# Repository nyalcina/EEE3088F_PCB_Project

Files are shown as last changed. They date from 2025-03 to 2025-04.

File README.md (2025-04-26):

# EEE3088F_PCB_Project_PTXNYA001_MNGAMO004
This repository details the progress of a Micromouse Power Board which was assigned by the EEE3088F teaching staff of the University of Cape Town. This project was completed in collaboration between Nyakallo Peete and Amos Manganye.
# Micro-Mouse Power Subsystem




---

## Overview

This repository contains the design files, schematics, and documentation for the **Power Subsystem** of the 2025 Micro-Mouse Project, developed as part of the EEE3088F course.

The Power Subsystem is responsible for:
- Accepting 9V input from a USB-C Power Delivery (PD) source.
- Charging a 3.7V 800mAh LiPo battery with selectable charging modes.
- Supplying regulated 3.3V and 5V outputs to system modules and motors.
- Controlling system power states through a low-leakage ON/OFF switch.
- Monitoring battery voltage and current via an I²C bus.
- Driving four motors (primary and auxiliary) for micro-mouse navigation.

---

## Features

- Provides regulated 5V and 3.3V outputs to supply all system modules, including processors, sensors, and external loads.
- Powers four motors (bidirectionally) via integrated motor driver outputs for primary and auxiliary drive control.
- Supports charging of a 3.7V 800mAh LiPo battery from a 9V USB-C input.
- Offers two selectable battery charging modes: low current mode (for extended battery life) and high current mode (for faster charging).
- Includes an ON/OFF control system that completely disables power rails when not in use, reducing standby current to less than 30μA.
- Enables real-time battery voltage and current monitoring through an I²C interface for improved system diagnostics and safety.
- Provides jumper-based power isolation and multiple test points throughout the system to simplify testing, debugging, and future upgrades.
- Designed for compact size, robustness, low cost, and manufacturability using JLCPCB basic part components.

---

## Tools Used

- KiCad 9.0 for schematic and PCB layout
- EasyEDA for footprints
- GitHub for version control and project documentation
- JLCBPB for manufacturing

---

## Authors

- **Amos Manganye**
- **Nyakallo Peete**

---

## Acknowledgements

- University of Cape Town (UCT) — Department of Electrical Engineering
- EEE3088F Teaching Staff

---

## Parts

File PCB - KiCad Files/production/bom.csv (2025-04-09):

Designator | Footprint | Quantity | Value | LCSC Part #
C10, C15 | 0603 | 2 | 100n | C14663
C11, C5, C8, C9 | 0603 | 4 | 100n | C14663
C12, C13, C16, C17, C23, C3 | 0603 | 6 | 10u | C19702
C14, C2 | 0603 | 2 | 2.2u | C23630
C19, C22, C24, C25 | 0603 | 4 | 10u | C19702
C21, C4 | 0603 | 2 | 1u | C5673
C27, C28, C29, C30, C31, C32 | 0603 | 6 | 22u | C59461
C6, C7 | 0603 | 2 | 10u | C19702
D1, D2, D4, D5 | 0603 | 4 | LED | C2286
D3 | 0603 | 1 | Red | C2286
J1 | JST_PH_S2B-PH-K_1x02_P2.00mm_Horizontal | 1 | Conn_01x02_Pin
J3 | PinHeader_2x16_P2.54mm_Vertical | 1 | Conn_02x16_Odd_Even
J4 | USB-C-SMD_TYPE-602-T3 | 1 | USB_C_Receptacle_PowerOnly_6P | C2927028
JP10, JP15, JP17, JP18, JP19, JP20, JP21, JP22, JP23, JP24, JP25, JP26, JP9 | SolderJumper-2_P1.3mm_Open_Pad1.0x1.5mm | 13 | Jumper_2_Small_Open
L1, L2 | 1008 | 2 | 2.2u | C5832372
R10 | 0603 | 1 | 56k | C23206
R11 | 0603 | 1 | 82k | C23254
R12, R22, R23, R8, R9 | 0603 | 5 | 0.22 | C3013347
R13 | 0805 | 1 | 5k6 | C4382
R14, R16, R19, R20, R28, R5 | 0603 | 6 | 1k | C21190
R2, R32, R33 | 0603 | 3 | 510k | C23192
R24, R27 | 0603 | 2 | 4.7k | C23162
R25 | 0603 | 1 | 1k8 | C4177
R29 | 0805 | 1 | 6k8 | C17772
R30, R31, R34, R6 | 0805 | 4 | 10k | C17414
R4 | 0805 | 1 | 470k | C17709
R7 | 0805 | 1 | 8.2k | C17828
SW1 | SW-TH_1MS1T1B1M1QES-5 | 1 | SW_Nidec_CAS-120A1 | C496154
TP19, TP2, TP20, TP21, TP22, TP24, TP25, TP3, TP32, TP33, TP34, TP35, TP36, TP37, TP38, TP39, TP4, TP40 | TestPoint_Pad_D1.0mm | 18 | TestPoint
U1 | IC_DRV8833PWPR | 1 | DRV8833PWPR | C50506
U10, U11 | TPS63020DSJR | 2 | TPS63020 | C15483
U13 | ESSOP-10_L4.9-W3.9-P1.0-LS6.0-TL-EP | 1 | CH224K | C970725
U2 | INA219AIDCNR | 1 | INA219AxDCN | C87469
U3, U5 | SOT-23-6_L2.9-W1.6-P0.95-LS2.8-BR | 2 | TPS22917DBV | C2681320
U4 | IC_DRV8833PWPR | 1 | DRV8833PWP | C50506
U6 | SOT-23-6_L2.9-W1.6-P0.95-LS2.8-BR | 1 | TS5A3159ADBVR | C128405
U9 | ESOP-8_L4.9-W3.9-P1.27-LS6.0-BL-EP | 1 | TP4056-42-ESOP8 | C16581

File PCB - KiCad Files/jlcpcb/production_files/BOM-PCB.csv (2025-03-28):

Comment | Designator | Footprint | LCSC | Quantity
100n | C10,C15 | C_0603_1608Metric_Pad1.08x0.95mm_HandSolder | C14663 | 2
TPS63020 | U10,U11 | TPS63020DSJR | C15483 | 2
47u | C8,C9 | C_0805_2012Metric_Pad1.18x1.45mm_HandSolder | C16780 | 2
10k | R30,R31,R32,R6 | R_0805_2012Metric_Pad1.20x1.40mm_HandSolder | C17414 | 4
6k8 | R29 | R_0805_2012Metric_Pad1.20x1.40mm_HandSolder | C17772 | 1
8.2k | R7 | R_0805_2012Metric_Pad1.20x1.40mm_HandSolder | C17828 | 1
10u | C11,C12,C3 | C_0603_1608Metric_Pad1.08x0.95mm_HandSolder | C197002 | 3
10u | C14,C19,C22 | C_0603_1608Metric_Pad1.08x0.95mm_HandSolder | C19702 | 3
1k | R14,R16,R28,R5 | R_0603_1608Metric_Pad0.98x0.95mm_HandSolder | C21190 | 4
LED | D1,D3,D4 | LED_0603_1608Metric_Pad1.05x0.95mm_HandSolder | C2286 | 3
4.7k | R24,R27 | R_0603_1608Metric_Pad0.98x0.95mm_HandSolder | C23162 | 2
2.2u | C16 | C_0603_1608Metric_Pad1.08x0.95mm_HandSolder | C23630 | 1
USB_C_Receptacle_PowerOnly_6P | J4 | USB_C_Receptacle_GCT_USB4110 | C2927028 | 1
200 | R10 | R_0805_2012Metric_Pad1.20x1.40mm_HandSolder | C2933534 | 1
1k8 | R25 | R_0603_1608Metric_Pad0.98x0.95mm_HandSolder | C4177 | 1
5k6 | R13 | R_0805_2012Metric_Pad1.20x1.40mm_HandSolder | C4382 | 1
SW_Nidec_CAS-120A1 | SW1 | SW-TH_1MS1T1B1M1QES-5 | C496154 | 1
DRV8833PWPR | U1,U4 | DRV8833PWPR | C50506 | 2
1u | C21,C4 | C_0603_1608Metric_Pad1.08x0.95mm_HandSolder | C5673 | 2
INA219AxDCN | U2 | INA219AIDCNR | C87469 | 1
2.2u | C13,C17 | C_0603_1608Metric_Pad1.08x0.95mm_HandSolder | C96446 | 2
TestPoint | TP36 | TestPoint_Pad_D1.0mm |  | 1
TestPoint | TP35 | TestPoint_Pad_D1.0mm |  | 1
TestPoint | TP34 | TestPoint_Pad_D1.0mm |  | 1
TestPoint | TP33 | TestPoint_Pad_D1.0mm |  | 1
TestPoint | TP32 | TestPoint_Pad_D1.0mm |  | 1
TestPoint | TP30 | TestPoint_Pad_D1.0mm |  | 1
TestPoint | TP26 | TestPoint_Pad_D1.0mm |  | 1
TestPoint | TP25 | TestPoint_Pad_D1.0mm |  | 1
TestPoint | TP24 | TestPoint_Pad_D1.0mm |  | 1
TestPoint | TP23 | TestPoint_Pad_D1.0mm |  | 1
TestPoint | TP22 | TestPoint_Pad_D1.0mm |  | 1
TestPoint | TP21 | TestPoint_Pad_D1.0mm |  | 1
TestPoint | TP20 | TestPoint_Pad_D1.0mm |  | 1
TestPoint | TP19 | TestPoint_Pad_D1.0mm |  | 1
TestPoint | TP14 | TestPoint_Pad_D1.0mm |  | 1
TestPoint | TP13 | TestPoint_Pad_D1.0mm |  | 1
TestPoint | TP12 | TestPoint_Pad_D1.0mm |  | 1
TestPoint | TP11 | TestPoint_Pad_D1.0mm |  | 1
TestPoint | TP10 | TestPoint_Pad_D1.0mm |  | 1
TestPoint | TP9 | TestPoint_Pad_D1.0mm |  | 1
TestPoint | TP8 | TestPoint_Pad_D1.0mm |  | 1
TestPoint | TP7 | TestPoint_Pad_D1.0mm |  | 1
TestPoint | TP6 | TestPoint_Pad_D1.0mm |  | 1
TestPoint | TP4 | TestPoint_Pad_D1.0mm |  | 1
TestPoint | TP3 | TestPoint_Pad_D1.0mm |  | 1
TestPoint | TP2 | TestPoint_Pad_D1.0mm |  | 1
0.22 | R12 | R2512 |  | 1
200 | R11 | R_0805_2012Metric_Pad1.20x1.40mm_HandSolder |  | 1
1.8k | R4 | R_0603_1608Metric |  | 1
1.8k | R2 | R_0603_1608Metric |  | 1
2.2u | L2 | L_1008_2520Metric_Pad1.43x2.20mm_HandSolder |  | 1
2.2u | L1 | L_1008_2520Metric_Pad1.43x2.20mm_HandSolder |  | 1
Jumper_2_Small_Open | JP18 | SolderJumper-2_P1.3mm_Open_Pad1.0x1.5mm |  | 1
Jumper_2_Small_Open | JP16 | SolderJumper-2_P1.3mm_Open_Pad1.0x1.5mm |  | 1
Jumper_2_Small_Open | JP15 | SolderJumper-2_P1.3mm_Open_Pad1.0x1.5mm |  | 1
Jumper_2_Small_Open | JP14 | SolderJumper-2_P1.3mm_Open_Pad1.0x1.5mm |  | 1
Jumper_2_Small_Open | JP11 | SolderJumper-2_P1.3mm_Open_Pad1.0x1.5mm |  | 1
Jumper_2_Small_Open | JP10 | SolderJumper-2_P1.3mm_Open_Pad1.0x1.5mm |  | 1
Jumper_2_Small_Open | JP9 | SolderJumper-2_P1.3mm_Open_Pad1.0x1.5mm |  | 1
Jumper_2_Small_Open | JP8 | SolderJumper-2_P1.3mm_Open_Pad1.0x1.5mm |  | 1
Jumper_2_Small_Open | JP7 | SolderJumper-2_P1.3mm_Open_Pad1.0x1.5mm |  | 1
Jumper_2_Small_Open | JP6 | SolderJumper-2_P1.3mm_Open_Pad1.0x1.5mm |  | 1
Jumper_2_Small_Open | JP5 | SolderJumper-2_P1.3mm_Open_Pad1.0x1.5mm |  | 1
Jumper_2_Small_Open | JP4 | SolderJumper-2_P1.3mm_Open_Pad1.0x1.5mm |  | 1
Jumper_2_Small_Open | JP3 | SolderJumper-2_P1.3mm_Open_Pad1.0x1.5mm |  | 1
Jumper_2_Small_Open | JP2 | SolderJumper-2_P1.3mm_Open_Pad1.0x1.5mm |  | 1
Jumper_2_Small_Open | JP1 | SolderJumper-2_P1.3mm_Open_Pad1.0x1.5mm |  | 1
Conn_02x16_Odd_Even | J3 | PinHeader_2x16_P2.54mm_Vertical |  | 1
Conn_01x02_Pin | J1 | JST_JWPF_B02B-JWPF-SK-R_1x02_P2.00mm_Vertical |  | 1
10u | C7 | C_0603_1608Metric_Pad1.08x0.95mm_HandSolder |  | 1
10u | C6 | C_0603_1608Metric_Pad1.08x0.95mm_HandSolder |  | 1
0.1u | C5 | C_0603_1608Metric_Pad1.08x0.95mm_HandSolder |  | 1
2.2u | C2 | C_0603_1608Metric_Pad1.08x0.95mm_HandSolder |  | 1
TestPoint | TP40 | TestPoint_Pad_D1.0mm |  | 1
TestPoint | TP39 | TestPoint_Pad_D1.0mm |  | 1
TestPoint | TP38 | TestPoint_THTPad_D2.5mm_Drill1.2mm |  | 1
TestPoint | TP37 | TestPoint_THTPad_D2.5mm_Drill1.2mm |  | 1
TestPoint | TP27 | TestPoint_Pad_D1.0mm |  | 1
0.22 | R19 | R2512 |  | 1
0.22 | R18 | R2512 |  | 1
0.22 | R17 | R2512 |  | 1
0.22 | R15 | R2512 |  | 1
0.22 | R9 | R2512 |  | 1
0.22 | R8 | R2512 |  | 1
Jumper_2_Small_Open | JP24 | SolderJumper-2_P1.3mm_Open_Pad1.0x1.5mm |  | 1
Jumper_2_Small_Open | JP23 | SolderJumper-2_P1.3mm_Open_Pad1.0x1.5mm |  | 1
Jumper_2_Small_Open | JP22 | SolderJumper-2_P1.3mm_Open_Pad1.0x1.5mm |  | 1
Jumper_2_Small_Open | JP21 | SolderJumper-2_P1.3mm_Open_Pad1.0x1.5mm |  | 1
Jumper_2_Small_Open | JP19 | SolderJumper-2_P1.3mm_Open_Pad1.0x1.5mm |  | 1
Jumper_2_Small_Open | JP17 | SolderJumper-2_P1.3mm_Open_Pad1.0x1.5mm |  | 1

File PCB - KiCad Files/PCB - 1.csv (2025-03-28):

Reference | Qty | Value | DNP | Exclude from BOM | Exclude from Board | Footprint | Datasheet
C2,C13,C16,C17 | 4 | 2.2u |  |  |  | Capacitor_SMD:C_0603_1608Metric_Pad1.08x0.95mm_HandSolder | https://jlcpcb.com/api/file/downloadByFileSystemAccessId/8568525238768373760
C3,C6,C7,C11,C12,C14,C19,C22 | 8 | 10u |  |  |  | Capacitor_SMD:C_0603_1608Metric_Pad1.08x0.95mm_HandSolder | https://jlcpcb.com/api/file/downloadByFileSystemAccessId/8579707107920437248,https://jlcpcb.com/api/file/downloadByFileSystemAccessId/8579707359440130048,~
C4,C21 | 2 | 1u |  |  |  | Capacitor_SMD:C_0603_1608Metric_Pad1.08x0.95mm_HandSolder | https://jlcpcb.com/api/file/downloadByFileSystemAccessId/8579707343598243840,https://jlcpcb.com/api/file/downloadByFileSystemAccessId/8586178237072617472
C5 | 1 | 0.1u |  |  |  | Capacitor_SMD:C_0603_1608Metric_Pad1.08x0.95mm_HandSolder | ~
C8,C9 | 2 | 47u |  |  |  | Capacitor_SMD:C_0805_2012Metric_Pad1.18x1.45mm_HandSolder | ~
C10,C15 | 2 | 100n |  |  |  | Capacitor_SMD:C_0603_1608Metric_Pad1.08x0.95mm_HandSolder | ~
D1,D4 | 2 | LED |  |  |  | LED_SMD:LED_0603_1608Metric_Pad1.05x0.95mm_HandSolder | https://jlcpcb.com/api/file/downloadByFileSystemAccessId/8550723991833485312
D3 | 1 | Red |  |  |  | LED_SMD:LED_0603_1608Metric_Pad1.05x0.95mm_HandSolder | https://jlcpcb.com/api/file/downloadByFileSystemAccessId/8550723991833485312
J1 | 1 | Conn_01x02_Pin |  |  |  | Connector_JST:JST_JWPF_B02B-JWPF-SK-R_1x02_P2.00mm_Vertical | ~
J3 | 1 | Conn_02x16_Odd_Even |  |  |  | Connector_PinHeader_2.54mm:PinHeader_2x16_P2.54mm_Vertical | ~
J4 | 1 | USB_C_Receptacle_PowerOnly_6P |  |  |  | Connector_USB:USB_C_Receptacle_GCT_USB4110 | https://jlcpcb.com/api/file/downloadByFileSystemAccessId/8589784804343648256
JP1,JP2,JP3,JP4,JP5,JP6,JP7,JP8,JP9,JP10,JP11,JP14,JP15,JP16,JP17,JP18,JP19,JP21,JP22,JP23,JP24 | 21 | Jumper_2_Small_Open |  |  |  | Jumper:SolderJumper-2_P1.3mm_Open_Pad1.0x1.5mm | ~
JP13 | 1 | Jumper_3_Open |  | Excluded from BOM |  |  | ~
L1,L2 | 2 | 2.2u |  |  |  | Inductor_SMD:L_1008_2520Metric_Pad1.43x2.20mm_HandSolder | ~
R2,R4 | 2 | 1.8k |  |  |  | Resistor_SMD:R_0603_1608Metric | ~
R5,R14,R16,R28 | 4 | 1k |  |  |  | Resistor_SMD:R_0603_1608Metric_Pad0.98x0.95mm_HandSolder | https://jlcpcb.com/api/file/downloadByFileSystemAccessId/8579705924167974912,https://jlcpcb.com/api/file/downloadByFileSystemAccessId/8579706098733010944
R6,R30,R31,R32 | 4 | 10k |  |  |  | Resistor_SMD:R_0805_2012Metric_Pad1.20x1.40mm_HandSolder | https://jlcpcb.com/api/file/downloadByFileSystemAccessId/8550723991833485312,https://jlcpcb.com/api/file/downloadByFileSystemAccessId/8562006748401074176,http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
R7 | 1 | 8.2k |  |  |  | Resistor_SMD:R_0805_2012Metric_Pad1.20x1.40mm_HandSolder | https://jlcpcb.com/api/file/downloadByFileSystemAccessId/8579705924167974912
R8,R9,R12,R15,R17,R18,R19 | 7 | 0.22 |  |  |  | Library:R2512 | ~
R10,R11 | 2 | 200 |  |  |  | Resistor_SMD:R_0805_2012Metric_Pad1.20x1.40mm_HandSolder | ~
R13 | 1 | 5k6 |  |  |  | Resistor_SMD:R_0805_2012Metric_Pad1.20x1.40mm_HandSolder | https://jlcpcb.com/api/file/downloadByFileSystemAccessId/8579706617560436736
R24,R27 | 2 | 4.7k |  |  |  | Resistor_SMD:R_0603_1608Metric_Pad0.98x0.95mm_HandSolder | https://jlcpcb.com/api/file/downloadByFileSystemAccessId/8579706098733010944
R25 | 1 | 1k8 |  |  |  | Resistor_SMD:R_0603_1608Metric_Pad0.98x0.95mm_HandSolder | https://jlcpcb.com/api/file/downloadByFileSystemAccessId/8579706147000926208
R29 | 1 | 6k8 |  |  |  | Resistor_SMD:R_0805_2012Metric_Pad1.20x1.40mm_HandSolder | https://jlcpcb.com/api/file/downloadByFileSystemAccessId/8579706637797543936
SW1 | 1 | SW_Nidec_CAS-120A1 |  |  |  | Library:SW-TH_1MS1T1B1M1QES-5 | https://www.nidec-components.com/e/catalog/switch/cas.pdf
TP2,TP3,TP4,TP6,TP7,TP8,TP9,TP10,TP11,TP12,TP13,TP14,TP19,TP20,TP21,TP22,TP23,TP24,TP25,TP26,TP27,TP30,TP32,TP33,TP34,TP35,TP36,TP39,TP40 | 29 | TestPoint |  |  |  | TestPoint:TestPoint_Pad_D1.0mm | ~
TP37,TP38 | 2 | TestPoint |  |  |  | TestPoint:TestPoint_THTPad_D2.5mm_Drill1.2mm | ~
U1 | 1 | DRV8833PWPR |  |  |  | Library:DRV8833PWPR | https://jlcpcb.com/api/file/downloadByFileSystemAccessId/8588881461298802689
U2 | 1 | INA219AxDCN |  |  |  | Library:INA219AIDCNR | https://jlcpcb.com/api/file/downloadByFileSystemAccessId/8586200525100486656
U3,U5 | 2 | TPS22917DBV |  |  |  | Nhlamolo.:SOT-23-6_L2.9-W1.6-P0.95-LS2.8-BR | http://www.ti.com/lit/ds/symlink/tps22917.pdf
U4 | 1 | DRV8833PWP |  |  |  | Package_SO:HTSSOP-16-1EP_4.4x5mm_P0.65mm_EP3.4x5mm_Mask2.46x2.31mm_ThermalVias | https://jlcpcb.com/api/file/downloadByFileSystemAccessId/8588881461298802689
U9 | 1 | TP4056-42-ESOP8 |  |  |  | Nhlamolo.:ESOP-8_L4.9-W3.9-P1.27-LS6.0-BL-EP-1 | https://www.lcsc.com/datasheet/lcsc_datasheet_2410121619_TOPPOWER-Nanjing-Extension-Microelectronics-TP4056-42-ESOP8_C16581.pdf
U10,U11 | 2 | TPS63020 |  |  |  | Library:TPS63020DSJR | chrome-https://jlcpcb.com/api/file/downloadByFileSystemAccessId/8588881940225540096
U12 | 1 | TS5A3159ADBVR |  |  |  | Nhlamolo.:SOT-23-6_L2.9-W1.6-P0.95-LS2.8-BR | http://www.ti.com/lit/ds/symlink/ts5a3159a.pdf
U13 | 1 | CH224K |  |  |  | Nhlamolo.:ESSOP-10_L4.9-W3.9-P1.0-LS6.0-TL-EP | https://jlcpcb.com/api/file/downloadByFileSystemAccessId/8588893165608296448

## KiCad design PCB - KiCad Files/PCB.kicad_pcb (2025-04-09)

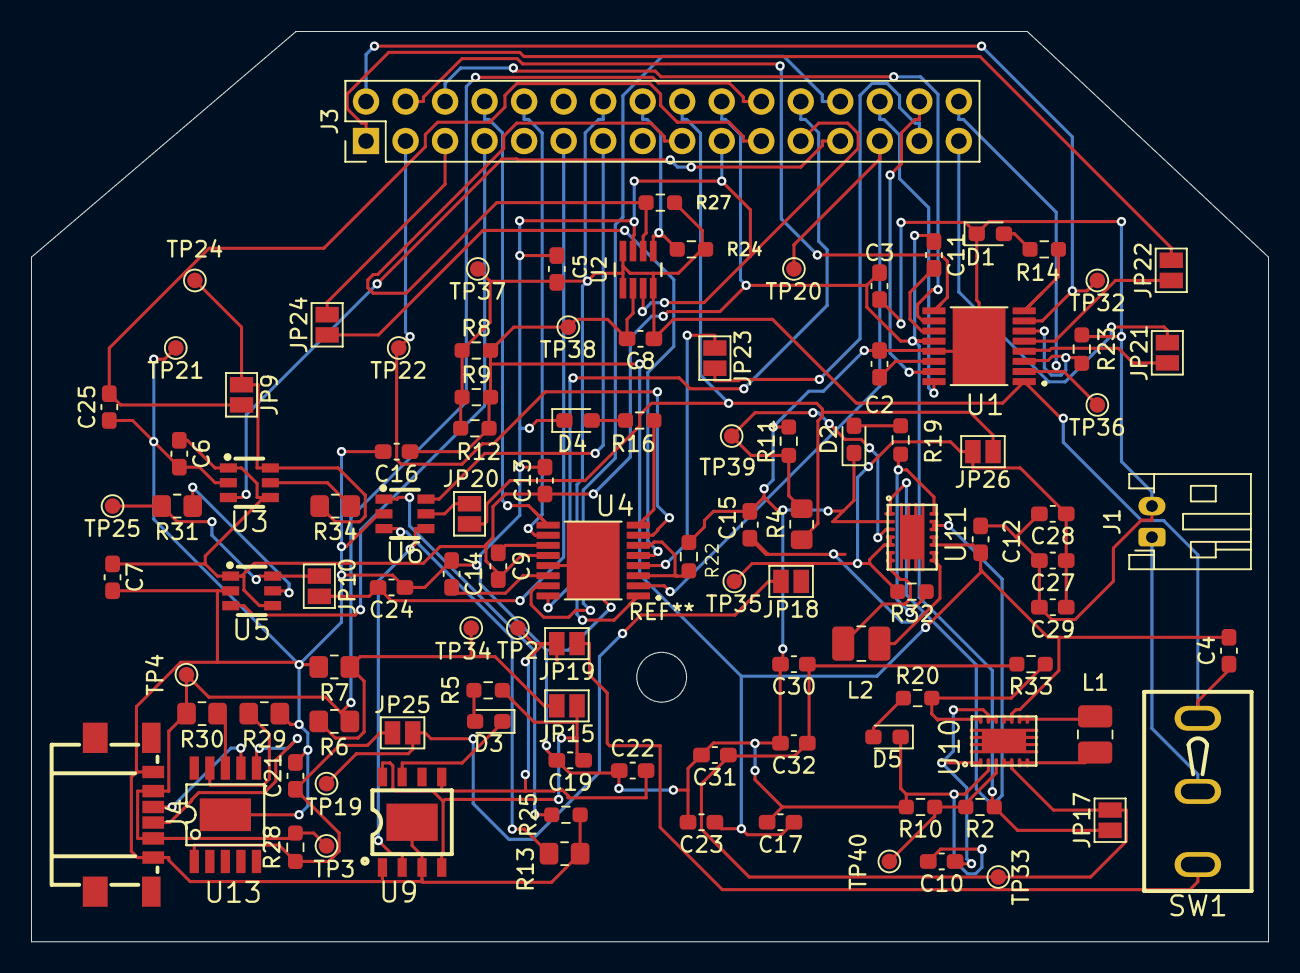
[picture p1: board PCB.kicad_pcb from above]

Board: 2 copper layers, 79.5 x 58.5 mm, 107 parts (0 on the bottom side), 78 nets.

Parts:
C2, C14: 2.2u; C_0603_1608Metric_Pad1.08x0.95mm_HandSolder
C3, C6, C7, C12, C13, C16, C17, C19, C22, C23, C24, C25: 10u; C_0603_1608Metric_Pad1.08x0.95mm_HandSolder
C4, C21: 1u; C_0603_1608Metric_Pad1.08x0.95mm_HandSolder
C5, C8, C9, C10, C11, C15: 100n; C_0603_1608Metric_Pad1.08x0.95mm_HandSolder
C27, C28, C29, C30, C31, C32: 22u; C_0603_1608Metric_Pad1.08x0.95mm_HandSolder
D1, D2, D4, D5: LED; LED_0603_1608Metric_Pad1.05x0.95mm_HandSolder
D3: Red; LED_0603_1608Metric_Pad1.05x0.95mm_HandSolder
J1: Conn_01x02_Pin; JST_PH_S2B-PH-K_1x02_P2.00mm_Horizontal
J3: Conn_02x16_Odd_Even; PinHeader_2x16_P2.54mm_Vertical
J4: USB_C_Receptacle_PowerOnly_6P; USB-C-SMD_TYPE-602-T3
JP9, JP10, JP15, JP17, JP18, JP19, JP20, JP21, JP22, JP23, JP24, JP25, JP26: Jumper_2_Small_Open; SolderJumper-2_P1.3mm_Open_Pad1.0x1.5mm
L1, L2: 2.2u; L_1008_2520Metric_Pad1.43x2.20mm_HandSolder
R2, R32, R33: 510k; R_0603_1608Metric_Pad0.98x0.95mm_HandSolder
R4: 470k; R_0805_2012Metric_Pad1.20x1.40mm_HandSolder
R5, R14, R16, R19, R20, R28: 1k; R_0603_1608Metric_Pad0.98x0.95mm_HandSolder
R6, R30, R31, R34: 10k; R_0805_2012Metric_Pad1.20x1.40mm_HandSolder
R7: 8.2k; R_0805_2012Metric_Pad1.20x1.40mm_HandSolder
R8, R9, R12, R22, R23: 0.22; R_0603_1608Metric_Pad0.98x0.95mm_HandSolder
R10: 56k; R_0603_1608Metric_Pad0.98x0.95mm_HandSolder
R11: 82k; R_0603_1608Metric_Pad0.98x0.95mm_HandSolder
R13: 5k6; R_0805_2012Metric_Pad1.20x1.40mm_HandSolder
R24, R27: 4.7k; R_0603_1608Metric_Pad0.98x0.95mm_HandSolder
R25: 1k8; R_0603_1608Metric_Pad0.98x0.95mm_HandSolder
R29: 6k8; R_0805_2012Metric_Pad1.20x1.40mm_HandSolder
SW1: SW_Nidec_CAS-120A1; SW-TH_1MS1T1B1M1QES-5
TP2, TP3, TP4, TP19, TP20, TP21, TP22, TP24, TP25, TP32, TP33, TP34, TP35, TP36, TP37, TP38, TP39, TP40: TestPoint; TestPoint_Pad_D1.0mm
U1: DRV8833PWPR; IC_DRV8833PWPR
U2: INA219AxDCN; INA219AIDCNR
U3, U5: TPS22917DBV; SOT-23-6_L2.9-W1.6-P0.95-LS2.8-BR
U4: DRV8833PWP; IC_DRV8833PWPR
U6: TS5A3159ADBVR; SOT-23-6_L2.9-W1.6-P0.95-LS2.8-BR
U9: TP4056-42-ESOP8; ESOP-8_L4.9-W3.9-P1.27-LS6.0-BL-EP
U10, U11: TPS63020; TPS63020DSJR
U13: CH224K; ESSOP-10_L4.9-W3.9-P1.0-LS6.0-TL-EP

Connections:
3V3 Out: J3.18, JP20.1 (A), JP26.1 (A), R4.1
5V Out: C3.1, C6.1, C7.1, C9.1, C11.1, C13.1, J3.20, JP17.1 (A), R2.1, U1.12 (VM), U3.1 (VIN), U3.4 (CT), U4.12 (VM), U5.1 (VIN), U5.4 (CT)
/3V3_Out: JP18.2 (B), JP25.2 (B), TP19.1
/CC1: J4.A5 (CC1), U13.7 (CC1)
/CC2: J4.B5 (CC2), U13.6 (CC2)
/M1AO2: JP21.1 (A), U1.4 (AOUT2)
/M2BO2: JP22.1 (A), U1.5 (BOUT2)
/M3AO2: JP23.1 (A), U4.4 (AOUT2)
/M4BO2: JP24.1 (A), U4.5 (BOUT2)
/SEN1: R23.2, U1.3 (AISEN), U1.6 (BISEN)
/SEN2: R22.2, U4.3 (AISEN), U4.6 (BISEN)
Battery: C4.1, C5.1, C8.1, J3.14, R8.1, R9.1, R12.1, R24.1, R27.1, SW1.1 (C), TP37.1, U1.1 (~SLEEP), U2.1 (IN+), U2.4 (VS), U2.8 (A1), U4.1 (~SLEEP)
CTRL_EXT_LOAD1: J3.25, U3.3 (ON)
CTRL_EXT_LOAD2: J3.7, U5.3 (ON)
Charger: JP19.1 (A), SW1.3 (A)
EXT_LOAD1_OUT: C25.2, J3.21, JP9.2 (B)
EXT_LOAD2_OUT: C24.2, J3.11, JP10.2 (B)
FAST_CHARGE_CTRL: J3.13, U6.6 (IN)
GND: C2.1, C3.2, C5.2, C6.2, C7.2, C10.2, C12.2, C13.2, C14.1, C15.2, C16.2, C17.2, C19.2, C21.2, C22.1, C23.2, C24.1, C25.1, C27.2, C28.2, C29.2, C30.2, C31.2, C32.2, D1.1 (K), D2.1 (K), D4.1 (K), D5.1 (K), J1.2, J3.19, J3.23, J4.A12 (GND), J4.B12 (GND), R7.2, R10.2, R11.2, R13.1, R22.1, R23.1, R25.1, R29.1, TP21.1, U1.13 (GND), U1.17 (GND), U2.3 (GND), U2.7 (A0), U3.2 (GND), U4.13 (GND), U4.17 (GND), U5.2 (GND), U6.2 (GND), U9.1 (TEMP), U9.3 (GND), U9.9 (EPAD), U10.2 (GND), U11.2 (GND), U13.11 (GND)
High_Voltage_(9V): J3.22, J4.A9 (VBUS), J4.B9 (VBUS), R6.1, R28.1, R30.2, TP3.1, TP4.1
I2C1_SCL: J3.16, R24.2, U2.5 (SCL)
I2C1_SDA: J3.17, R27.2, U2.6 (SDA)
Load_Supply: C4.2, C8.2, C12.1, C16.1, C17.1, C23.1, R8.2, R9.2, R12.2, TP38.1, U2.2 (IN-), U10.10 (VIN2), U10.11 (VIN1), U11.10 (VIN2), U11.11 (VIN1)
MOTOR1_A_OUT: J3.32, TP36.1, U1.2 (AOUT1)
MOTOR1_B_OUT: J3.31, JP21.2 (B)
MOTOR1_CTRL1: J3.28, U1.16 (AIN1)
MOTOR1_CTRL2: J3.30, U1.15 (AIN2)
MOTOR2_A_OUT: J3.2, TP32.1, U1.7 (BOUT1)
MOTOR2_B_OUT: J3.1, JP22.2 (B)
MOTOR2_CTRL1: J3.4, U1.9 (BIN1)
MOTOR2_CTRL2: J3.6, U1.10 (BIN2)
MOTOR3_A_OUT: J3.27, TP20.1, U4.2 (AOUT1)
MOTOR3_B_OUT: J3.29, JP23.2 (B)
MOTOR3_CTRL1: J3.24, U4.16 (AIN1)
MOTOR3_CTRL2: J3.26, U4.15 (AIN2)
MOTOR4_A_OUT: J3.3, TP22.1, U4.7 (BOUT1)
MOTOR4_B_OUT: J3.5, JP24.2 (B)
MOTOR4_CTRL1: J3.8, U4.9 (BIN1)
MOTOR4_CTRL2: J3.10, U4.10 (BIN2)
unnamed: D1.2 (A), R14.1
unnamed: D2.2 (A), R19.1
unnamed: D3.2 (A), R5.2
unnamed: D3.1 (K), U9.7 (~CHRG)
unnamed: D4.2 (A), R16.1
unnamed: D5.2 (A), R20.1
unnamed: J1.1, SW1.2 (B)
unnamed: JP9.1 (A), R34.2, TP24.1, U3.6 (VOUT)
unnamed: JP10.1 (A), R31.2, TP25.1, U5.6 (VOUT)
unnamed: C19.1, JP15.1 (A), R5.1, U9.4 (V_{CC}), U9.8 (CE)
unnamed: JP15.2 (B), R6.2, R7.1, TP34.1
unnamed: C30.1, C31.1, C32.1, JP17.2 (B), R33.2, TP33.1, U10.4 (VOUT1), U10.5 (VOUT2)
unnamed: C22.2, JP19.2 (B), TP2.1, U9.5 (BAT)
unnamed: JP20.2 (B), U6.5 (V+)
unnamed: C21.1, JP25.1 (A), R28.2, U13.1 (VDD)
unnamed: C27.1, C28.1, C29.1, JP26.2 (B), R32.2, TP35.1, U11.4 (VOUT1), U11.5 (VOUT2)
unnamed: L1.1, U10.6 (L2), U10.7 (L2)
unnamed: L1.2, U10.8 (L1), U10.9 (L1)
unnamed: L2.1, U11.6 (L2), U11.7 (L2)
unnamed: L2.2, U11.8 (L1), U11.9 (L1)
unnamed: C11.2, U1.11 (VCP)
unnamed: C2.2, U1.14 (VINT)
unnamed: R14.2, U1.8 (~FAULT)
unnamed: R34.1, U3.5 (QOD)
unnamed: C9.2, U4.11 (VCP)
unnamed: C14.2, U4.14 (VINT)
unnamed: R16.2, U4.8 (~FAULT)
unnamed: R31.1, U5.5 (QOD)
unnamed: U6.4 (COM), U9.2 (PROG)
unnamed: R13.2, U6.3 (NC)
unnamed: R25.2, U6.1 (NO)
unnamed: C10.1, U10.1 (VINA), U10.12 (EN), U10.13 (PS/SYNC)
unnamed: R2.2, R10.1, TP40.1, U10.3 (FB)
unnamed: R20.2, R33.1, U10.14 (PG)
unnamed: C15.1, U11.1 (VINA), U11.12 (EN), U11.13 (PS/SYNC)
unnamed: R4.2, R11.1, TP39.1, U11.3 (FB)
unnamed: R19.2, R32.1, U11.14 (PG)
unnamed: R29.2, U13.9 (CFG1)
unnamed: R30.1, U13.8 (VBUS)

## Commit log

2025-03-12 Add kicad files
    [PCB.kicad_pcb, PCB.kicad_sch]
2025-03-12 Add Project Documentation
    [PCB.kicad_sch]
2025-03-24 Add ICs without configuration
    [PCB.kicad_sch]
2025-03-24 Pin Headers added with global labels
    [PCB.kicad_sch, untitled.kicad_sch]
2025-03-24 Fix header labels and Add Charger IC
    [PCB.kicad_sch]
2025-03-24 Semi configured schematic
    [PCB.kicad_sch]
2025-03-25 Changes to Layout
    - An additional sheet was added
    - ptxnya001's modules were placed into demarcated areas on her sheet
    - ptxnya001's modules were given brief descriptions
    [AMOS's section.kicad_sch, PCB.kicad_sch]
2025-03-25 Updated Voltage regulator circuit
    [AMOS's section.kicad_sch, PCB.kicad_sch]
2025-03-25 IC footprints and H-bridge test points
    [PCB.kicad_pcb, PCB.kicad_sch]
2025-03-26 Add Chrarging circuit, USB integration, and pin headers
    [AMOS's section.kicad_sch, PCB.kicad_sch]
2025-03-26 Taken back
    This commit is to allow my partner to add his schematic to my previous version.
    [AMOS's section.kicad_sch, PCB.kicad_sch]
2025-03-26 Add Charging circuit and USB integration
    [AMOS's section.kicad_sch, PCB.kicad_sch]
2025-03-26 Add 2x16 connectors
    [AMOS's section.kicad_sch, PCB.kicad_sch]
2025-03-26 Add digital switch for fast charging
    [AMOS's section.kicad_sch]
2025-03-26 Fix negotiator configuration
    [AMOS's section.kicad_sch]
2025-03-27 Add H-Bridge footprints
    [AMOS's section.kicad_sch, PCB.kicad_pcb, PCB.kicad_sch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]
2025-03-27 Add footprint for charging circuit and usb integration
    [AMOS's section.kicad_sch, PCB.kicad_sch]
2025-03-27 Fix electrical faults
    [PCB.kicad_sch]
2025-03-27 Dummy Commit
    [PCB.kicad_sch]
2025-03-27 Fix passive components footprints
    [AMOS's section.kicad_sch]
2025-03-27 Error Resolutions
    [AMOS's section.kicad_sch, PCB.kicad_sch]
2025-03-28 Confirm LCSC numbers
    [CPL-PCB.csv, PCB-CuBottom.gbr, PCB-CuTop.gbr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]
2025-03-28 Double Checking footprints and LCSC numbers
    [AMOS's section.kicad_sch, PCB.kicad_sch]
2025-03-28 Before PCB layout
    [BOM-PCB.csv, PCB - 1.csv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]
2025-03-28 Begining of PCB Layout
    [PCB.kicad_pcb, PCB.kicad_sch]
2025-04-04 Fix PCB layout
    [PCB.kicad_pcb, PCB.kicad_sch]
2025-04-07 Final updates to the INA219, Motor controllers, Voltage regulators and External load switching circuit
    [PCB.kicad_sch]
2025-04-07 Addition of the RQOD resistor
    The resistor between the QOD and VOUT pins was mistakenly omitted.
    [PCB.kicad_sch]
2025-04-08 Final Component checks before routing
    [PCB.kicad_sch]
2025-04-09 Placing All components onto the silkscreen
    [PCB.kicad_pcb, PCB.kicad_sch]
2025-04-25 Final Schematic edits
    [AMOS's section.kicad_sch, PCB.kicad_sch]
2025-04-25 Organised Git Files
    [AMOS's section.kicad_sch, BOM-PCB.csv, PCB - 1.csv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]

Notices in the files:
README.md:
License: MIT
